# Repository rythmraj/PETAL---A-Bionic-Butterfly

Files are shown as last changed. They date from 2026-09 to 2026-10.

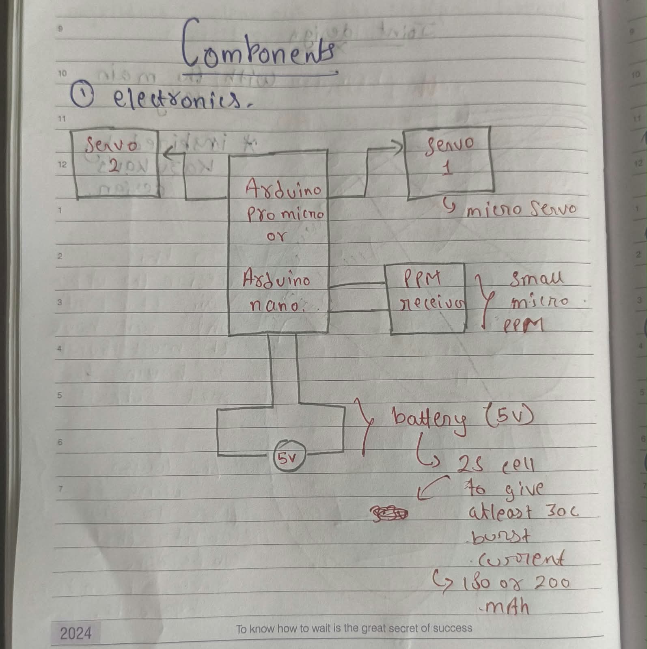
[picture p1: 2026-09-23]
Diary notes/WhatsApp Image 2026-09-23 at 20.36.07 (2).jpeg

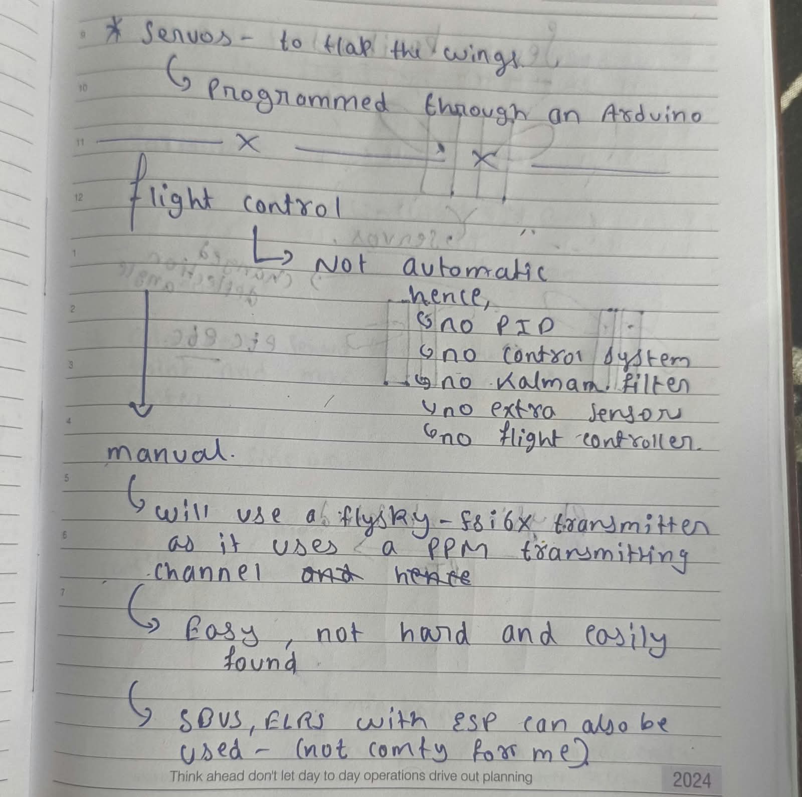
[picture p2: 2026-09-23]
Diary notes/WhatsApp Image 2026-09-23 at 20.32.57.jpeg

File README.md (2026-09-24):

Petal - A Bionic Butterfly

WhatsApp Image 2026-09-22 at 06 52 32 (1)

A small RC-controlled bionic butterfly built around an Arduino pro micro, two micro servos, and a FlySky receiver.

The project explores how a simple mechanical system can reproduce the flapping motion of a butterfly using coordinated servo movement. The firmware uses mathematical waveforms, including sine and triangular waves, to generate the wing motion.

The project is designed to be lightweight, reproducible, and easy to modify.

---

What Makes This Project Different?

Instead of simply reproducing an existing bionic butterfly build, this project focuses on understanding, modifying, and documenting the complete system, which provides guides for troubleshooting:

- Customised CAD design



- Personalised mechanical components
- Two-servo wing actuation

WhatsApp Image 2026-09-19 at 07 02 00 (2)

- Arduino pro micro or nano control
- FlySky RC control
- Sine-wave based wing motion
- Triangular-wave based wing motion
- Adjustable flapping parameters
- Documented electronics and wiring
- Reproducible build instructions
- Development and testing documentation

The project was developed iteratively, starting with individual servo tests and progressing toward the complete butterfly system.

---

Why I Made It

The idea for the Bionic Butterfly came to me after I saw some children in a park playing with butterflies and trying to catch them. It made me curious about whether I could recreate the movement of a butterfly using engineering rather than trying to replicate the entire animal. Later that same day, I came across mechanical design ideas and projects on GitHub, which inspired me to start designing my own version.
I wanted to understand how biological motion could be recreated using relatively simple electronics and mechanical components.
A butterfly is an interesting engineering problem because its wings require coordinated, repeated motion while remaining lightweight.
This project is also an experiment in learning engineering through building, documenting failures, and improving the design.

Inspiration:
Ken Jhonson's first butterfly design


Kazuhiko Kakuta - Butterfly and Ornitohopter designs.

Festo robotics company - Bionic blue butterfly


S-Diy and Ctorque tech youtube channel's modern design.

---
 How It Works

The butterfly uses two micro servos to drive the wings.
The Arduino Nano receives control input from a FlySky receiver and generates the corresponding servo positions.
The firmware can generate different motion profiles, like a sine wave,
a sinusoidal function is used to create smooth periodic wing movement.
servo_position = center + amplitude × sin(phase) (kinda like this, check the diary section for more info and also the firmware)
This produces relatively smooth acceleration and deceleration throughout the wing stroke.

---

Hardware

Component| Quantity

Arduino pro micro | 1

Micro servos (PTK 7465MG) | 2

FlySky receiver (FS - A8S) | 1

Flysky transmitter (flysky fsi6) | 1

2S battery (lipo, 180 or 220 or even 350 mAh, but should be lightweight, under 11-12g) (25c or 30c or higher) | 1

Butterfly mechanical structure| 1

See ""BOM.csv"" (BOM.csv) for the complete bill of materials, links, and total cost.

---

Electronics

The Arduino pro micro acts as the main controller.
The FlySky receiver provides the control input, while the two micro servos provide the mechanical actuation.
The complete wiring diagram is available here:
"Wiring Diagram" (Electronics/wiring_diagram.png)

For detailed wiring and connection information, see:
- ""Electronics/wiring_notes.md"" (Electronics/wiring_notes.md)

---

 CAD

The project contains the editable CAD source files, exported STEP files, and STL files required for fabrication.

CAD files

- "CAD/STL/" — printable STL files

---

Firmware

The firmware is written for the Arduino pro micro.

Main firmware:
The firmware controls the two servos and implements the wing-motion algorithms.

Current motion modes include:
- Sine wave
- Triangular wave (to be done)

The firmware is intentionally documented so that parameters such as amplitude, frequency, center position, and control response can be modified.

Development & Testing

The project was developed incrementally rather than assembling everything at once.

The development process included:

1. Testing individual servos 
2. Testing servo range and direction 
3. Testing Arduino control 
4. Testing receiver input ( to be done )
5. Developing the wing-motion algorithm 
6. Comparing motion profiles ( to be done )
7. Integrating the mechanical system ( to be done )
8. Testing the complete butterfly ( to be done )
9. Recording problems and modifications ( to be done )
10. Preparing the final reproducible design ( to be done )

Early experiments and test code are available in:

""Initial_Test/"" (Initial_Test/)

Development photographs and screenshots are available in:

""Images/"" (Images/)

---
 Development Diary (Highly recommend checking it to understand the workflow)

I maintained notes during the research and development process.
this is like a design history file, research to modification to questions, everything is there.
Scanned/photographed diary pages are available in:
"" Diary/ "" (Diary/)

The diary documents the development process, research, decisions, experiments, and iterations behind the project.

---

---

References & Credits

This project was developed while studying existing open-source bionic butterfly projects and related designs.
Existing work was used as reference and inspiration rather than being presented as original work.
Where an existing design was modified or incorporated, the original creator and source are credited in:
""Documentation/references.md"" (Documentation/references.md)
S-DiY Bionic Butterfly
The S-DiY bionic butterfly project was studied as a reference for the general mechanical/electronic concept.
Ctorque CAD Model
A CTorque model was used as a starting or perhaps as reference point for part of the CAD development. The modified or personalised version in this repository is identified in the CAD documentation.

All third-party work remains credited to its respective creators.

---

License

See ""LICENSE"" (LICENSE) for the licensing information applicable to the original work in this repository.

Third-party designs and references remain subject to their respective original licenses.

---

Project Status

Current status: Functional prototype / final design in development
The project has progressed from individual component testing to an integrated bionic butterfly system.
In the repository there are a few ( to be done ) marks present, as that is a future goal and will be completed as soon as possible to completely finish the build.

---

Author

Rythm Raj
Student / independent maker
This project was built as a personal engineering project to learn mechanical design, electronics, embedded programming, and iterative prototyping.

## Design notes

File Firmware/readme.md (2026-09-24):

# Firmware

## Hardware

- Arduino Pro Micro
- 2 micro servos
- FlySky receiver

## Motion Modes

The firmware currently supports:

1. Sine-wave wing motion
2. Triangular-wave wing motion (to be added)

## Uploading

1. Open `bionic_butterfly.ino` in Arduino IDE.
2. Select Arduino pro micro.
3. Select the appropriate processor/bootloader.
4. Select the correct COM/serial port.
5. Upload.

## Configuration

Motion parameters can be adjusted in the source code.

These include parameters such as:

- Servo center
- Servo amplitude
- Motion frequency
- Receiver input range
- Servo limits

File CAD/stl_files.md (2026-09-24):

my design changes:

instead of copying their design I went on to modify both of them according to my needs, 
for ctorque's design, I changes some dimensions and added "PETAL" engraving on the body of the desing;











Similarly with sdiy's design, i realised it could be a little pointy and sharp so i added my own iterations on it, used his dimension analysis only.
however, this design is not tested before, after testing if any changes required, i will post them here.



















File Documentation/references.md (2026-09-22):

References & Attribution

This project was developed through research into existing bionic butterfly projects, open-source CAD models, electronics implementations, and servo-control techniques.

I have intentionally documented external work used as references so that the original creators are not presented as part of my original work.

---

S-DiY Bionic Butterfly

The S-DiY bionic butterfly project was studied to understand the general concept of a two-servo bionic butterfly and its mechanical/electronic implementation.

The project influenced my understanding of the overall mechanism, but the firmware and implementation in this repository were developed separately.

Original project:

[(https://www.youtube.com/@SDiYchannel01)]

---

Ctorque CAD Model

A Ctorque CAD model was used as a starting/reference model for part of the mechanical design.
I modified the relevant model for my implementation and personalised the design by adding my own identifying/detail features.
Original model:

[https://www.youtube.com/@CTorque]

The repository does not claim the original base geometry as my original work.

---

Firmware References

The firmware was developed independently for this project. (Inspired by sdiy and kazukaku)
The implementation uses periodic mathematical functions, including sine-wave and triangular-wave motion, to control the servos.
Any external code, libraries, or algorithms used directly in the final implementation are listed below.



---

Other References / Research:

https://www.researchgate.net/figure/Butterfly-wing-structure-and-standard-of-length-measurement-A-Structures-and-names-of_fig1_355461952

https://dl.acm.org/doi/10.1145/3756423.3756506

https://dl.acm.org/doi/full/10.1145/3510459

---

Original Work in This Repository

The following parts represent my own project work:

- Project integration
- Mechanical modifications
- Personalised CAD features
- Electronics integration
- Wiring implementation
- Firmware implementation
- Servo-control logic
- Testing
- Iteration
- Build documentation
- Development diary
- Project photography and documentation

The repository distinguishes between referenced work and my modifications wherever applicable.

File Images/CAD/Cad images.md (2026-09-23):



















NOTE - DESIGNS ARE INSPIRED BY S-DIY AND CTORQUE CHANNEL, MAKE SURE TO CHECK THEM OUT FOR MORE PRECISE DIMENSIONS BASED DESIGNS.
(I cannot copy and paste their work here)







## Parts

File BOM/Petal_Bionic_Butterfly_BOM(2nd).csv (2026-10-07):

 | PETAL - A BIONIC BUTTERFLY (BOM)
 | DATE - 08-10-2026 |  | AUTHOR: RYTHM RAJ (@rythmmm on pixl)
S.NO. | Name | Quantity | buying link | price in INR | price in USD
1
2 | Arduino Pro Micro | 1 | https://www.amazon.in/gp/product/B0H9YZ9P35/ref=ewc_pr_img_1?smid=A31S66SMNGFXRB&psc=1 | 580 inr | 5.99 usd
3 | PTK 7465 MG-D 9g Servo | 2 | LOCAL SELLER (SCREENSHOTS ATTACHED) | 1500*2 = 3000 inr | 31.01 usd
4 | FlySky FS-i6 2.4GHz 6 Channel RC Transmitter | 1 | https://robu.in/product/flysky-fs-i6-2-4g-6ch-ppm-rc-transmitter-with-fs-ia6b-receiver/?gad_source=1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 | 5699 inr | 58.90 usd
5 | FlySky FS-A8S 2.4G 8CH Mini Receiver | 1 | https://www.amazon.in/gp/product/B0DP4WZFP2/ref=ox_sc_act_title_2?smid=AJ6SIZC8YQDZX&psc=1 | 1831 inr | 18.92 usd
6 | FABRIC(1) - Flowers Waterproof Floral Wrapping Paper | 1 | https://www.amazon.in/gp/product/B0DHSC99L6/ref=ewc_pr_img_1?smid=A11SOKBUQ5CS65&th=1 | 285 inr | 2.97 usd
7 | Carbon Fibre Rod (Solid) 1.5mm * 1000mm | 3 | https://robu.in/product/pultruded-carbon-fibre-rod-solid-1-5mm-1000mm-pack-of-4/ | 579*3 = 1737 inr | 17.95 usd
8 | Carbon Fibre Rod (Solid) 0.8mm * 1000mm | 2 | https://robu.in/product/pultruded-carbon-fibre-rod-solid-0-8mm-1000mm/ | 529*2 = 1058 inr | 10.93 usd
 | Battery Charger | 1 | https://www.amazon.in/gp/product/B0H41GF89X/ref=ewc_pr_img_1?smid=A3K0FQVTANK4PI&psc=1 | 299 inr | 3.09 usd
14 | Battery - 2s lipo, 180 or 220 mAh (2 batteries) | 2 | CANNOT FIND ONLINE, OFFLINE MARKET (RECEIPT WILL BE PRODUCED) [HARDWARE GRANT CAN COVER IT] |  | 10 usd
16 | 3d printing of parts (5 parts in total) | 5 | CANNOT FIND ONLINE, OFFLINE MARKET (RECEIPT WILL BE PRODUCED) [3D PRINTING GRANT CAN COVER IT] |  | 10 usd
17 | Wood laser cnc for one design | 1 | CANNOT FIND ONLINE, OFFLINE MARKET (RECEIPT WILL BE PRODUCED) [3D PRINTING GRANT CAN COVER IT] |  | 10 usd
 |  |  | Total = | 14,489 inr | 179.96 USD WITH GRANTS
 |  |  |  |  | 149.76 USD WITHOUT GRANTS

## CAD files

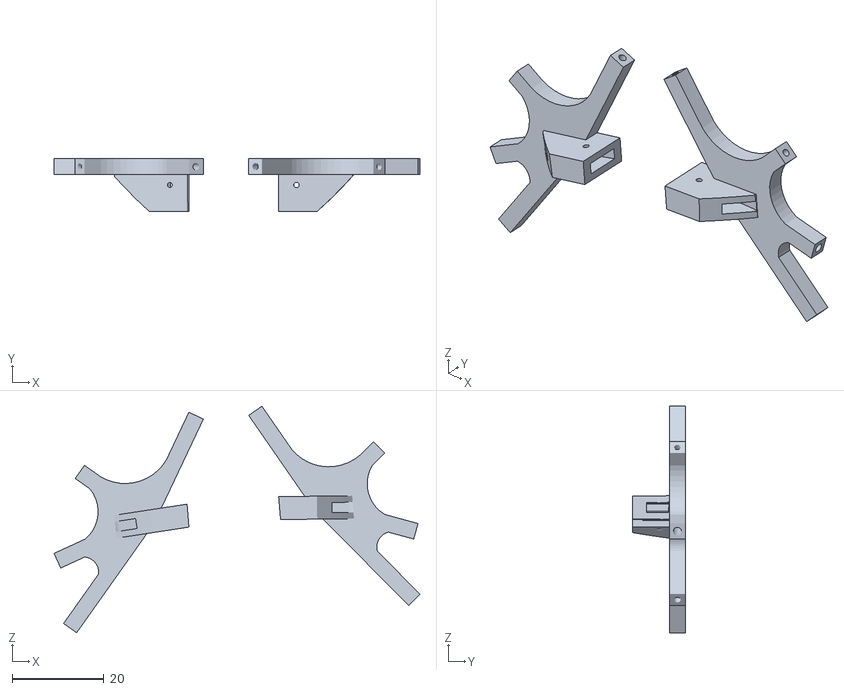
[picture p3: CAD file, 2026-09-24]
CAD/wing_mount.STL
79.7 x 11.5 x 49.3

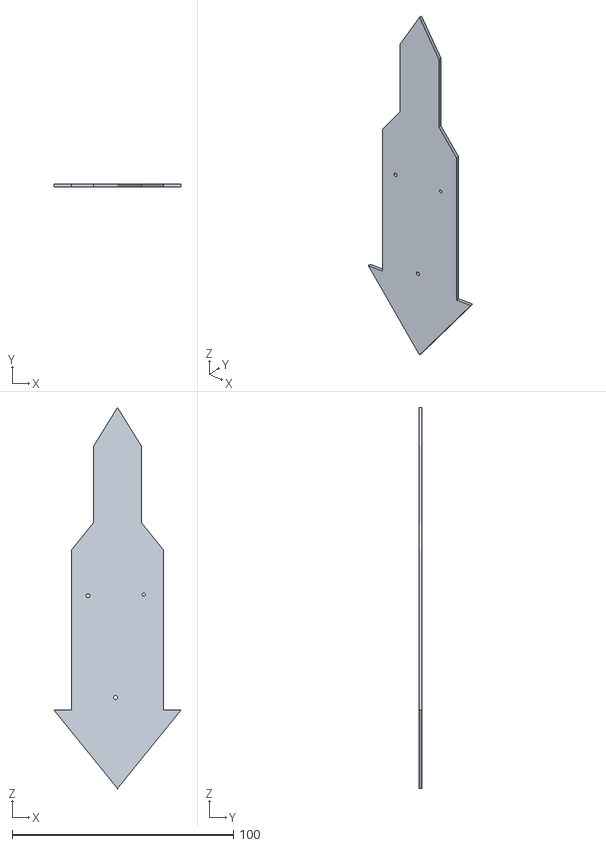
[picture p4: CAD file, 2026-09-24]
CAD/Pointy_design.stl
57.3 x 1.50 x 172.0

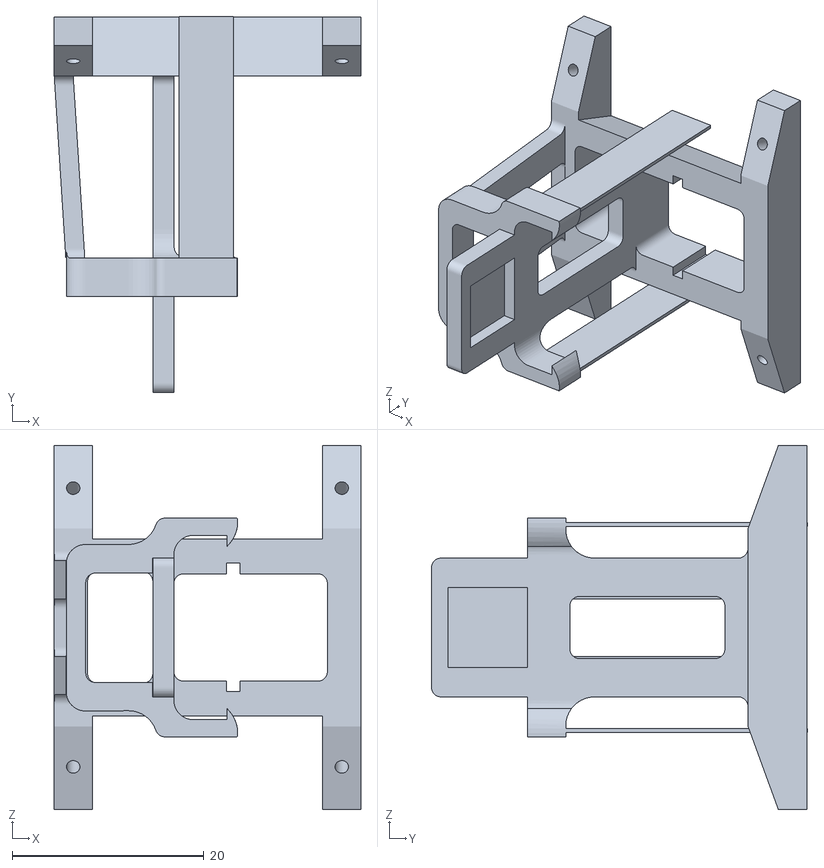
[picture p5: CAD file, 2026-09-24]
CAD/FC_Mount_V5_PETAL (1).stl
32.0 x 39.2 x 38.0

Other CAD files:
CAD/FC_Mount_V5_PETAL (1).f3d
CAD/Pointy_design.f3d

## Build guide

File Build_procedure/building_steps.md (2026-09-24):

IMPORTANT: THIS ENTIRE FILE IS IN "to be done" segment, as im still working to build the model, and when ill make it fly, 
i will update this as well with all the changes from
troubleshooting to change in wiring to everything.
I will also add images regarding the procedure in this file,

# Build Procedure

## 1. Print the parts

If you are going with the pointy design, print it, if you are going with fc design, print it as well.

## 2. Prepare the servos

mount the servos while matching the holes present on the body

## 3. Assemble the wing mechanism

use carbon fiber rods (1 to 0.5 mm as supports to assemble the wing) and then connect it to the connector

## 4. Install the Arduino

install the arduino board with the battery on to the body.

## 5. Install the receiver

install the receiver on the electronics as well (MKAE SURE TO REMOVE THE I-BUS OR S-BUS CHANNEL FROM THE RECEIVER, JUST REMOVE THE WIRE)

## 6. Wire the electronics

preferebly solder the wires to reduce weight of extras, connect it as shown on the diagram. 

## 7. Upload firmware

find the firmware on the firmware file in the repo.

## 8. Bind the transmitter

click on the binding button, and when the led on the receiver stops blinking and flashes a hard light, your transmitter is now binded with the receiver

## 9. Test the servos

the servos will move in opposite direction from each other and will change speed, pitch, frequency and angle as you change it on the respective channels on the transmitter.

## 10. Test the complete butterfly

(to be done)

## 11. Troubleshooting

Servo moving in wrong direction:
(to be done)

Servo jitter:
(to be done)

Wing hitting body:
(to be done)

Receiver not responding:
...

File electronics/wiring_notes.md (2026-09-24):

WhatsApp Image 2026-09-25 at 02 13 01

a 1S battery can also be used with a buck convertor (stepup)



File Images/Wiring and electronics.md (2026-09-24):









WIRING :



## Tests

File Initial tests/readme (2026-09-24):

# Initial Testing

IF YOU ARE USING THIS REPOSITORY TO BUILD YOUR OWN BIONIC BUTTERFLY, YOU DON'T NEED TO USE THIS FOLDER, ITS ONLY HERE TO DOCUMENT MY PROCESS.

This folder contains early experiments performed before the final firmware.

These tests were used to verify:

- Servo movement
- Servo direction
- Servo limits
- Arduino output
- Receiver input
- Initial wing-motion concepts

These files are development experiments and are not necessarily the final firmware.

The final implementation is located in `Firmware/`.

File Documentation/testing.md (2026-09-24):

This document is there to monitor the testing,
this will contain failures that (if) will happen during and after the building of petal
it will have the test name, expected result and the actual outcome
like:
test - left servo
expected - smooth movement
actual - (could be a positive result or a failure, both will be noted down)
its like journal with more technical terms and procedure,
if something failed, i will document the failure and  tell what i changed, this will even help other people who want to build their own bionic butterfly.

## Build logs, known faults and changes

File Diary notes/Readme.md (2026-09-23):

Development Diary

This folder contains photographs/scans of my physical development diary.

I used the diary to record research, ideas, calculations, design decisions, experiments, problems, and changes made during development.

The pages are kept in chronological order where possible.

The diary is included as development documentation rather than as a formal technical specification. The final technical information is maintained in the main project documentation.

Contents

- Research notes
- Initial ideas
- Mechanical design notes
- Servo experiments
- Firmware experiments
- Electronics notes
- Problems encountered
- Design changes
- Testing observations
- Future improvements

The photographs/scans are kept as close to the original notes as possible.

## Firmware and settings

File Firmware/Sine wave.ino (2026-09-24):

//This is the Sine wave version. The mechanism makes the servos move fast in the middle and slow down at the edges. 
// The advantage is a more lifelike flapping motion that saves energy, though the flapping speed and power are weaker than the Triangle wave version.
// Max Flap Angle	flapAmplitude	40 - 85	Sets the peak travel (degrees) from the 90° center point. Values above 80 may strain mechanical linkages.
// Pulse Width	attach(pin, 500, 2500)	500 - 2500 us	Extends physical servo travel. Verify that your servos support 2500us to avoid motor burnout.
// Flapping Speed	speedFactor	50 - 150	Mapped to the Throttle channel. Defines the phase increment per loop (Sine/Triangle wave frequency).
// i also added a lot of comments to actually explain the code to someone who has no idea about how it works.


/*
 PETAL - BIONIC BUTTERFLY
 
 
 
  RC Channels:
   CH1 -> steering
   CH2 -> elevator
   CH3 -> flapping speed
   CH5 -> steering trim
   CH6 -> pitch trim / perch control 
   CH7 -> perch switch (or any other emote maybe, perch is isnpired by s-diy)
 */

#include <Servo.h>
#include <PPMReader.h>


// pin config

const byte PPM_PIN = 3;

const byte LEFT_SERVO_PIN  = 9;
const byte RIGHT_SERVO_PIN = 10;


// ppm config

const byte CHANNEL_COUNT = 7;

PPMReader ppm(PPM_PIN, CHANNEL_COUNT);


// servo config

Servo servoLeft;
Servo servoRight;

const int CENTER_ANGLE = 90;


// flapping conif

// maxm movement away from center basically,
// 65 means -
// Left:  90 + 65 = 155 degrees
// Right: 90 - 65 = 25 degrees
// the servos move opposite each other,
// this produces the wing-flapping motion, duhhh(?) :>

const int FLAP_AMPLITUDE = 65;

// max pitch trim correction
const int MAX_PITCH_TRIM = 20;

// flight state

float phase = 0.0;
float perchPhase = 0.0;

float currentOffset = 0.0;

bool isPerching = false;
bool wasFailsafe = true;


// servo position tracking

int lastLeftPosition  = CENTER_ANGLE;
int lastRightPosition = CENTER_ANGLE;


// ppm filtering

// stored channel values are like;
// Index 0 = CH1
// Index 1 = CH2
// and so onto
// Index 6 = CH7

int lastChannelValues[CHANNEL_COUNT] = {
  1500,
  1500,
  1500,
  1500,
  1500,
  1500,
  1500
};


// lets ignore the small ppm fluctuations.
const int PPM_DEADBAND = 3;

// serial debugging

unsigned long lastLogTime = 0;

const unsigned long LOG_INTERVAL = 1000;


// SETUP (IMP)

void setup() {

  Serial.begin(115200);

  // attaching servos
  // 500–2500 gives the servo library a wide usable pulse range

  servoLeft.attach(LEFT_SERVO_PIN, 500, 2500);
  servoRight.attach(RIGHT_SERVO_PIN, 500, 2500);


  // start both servos at their neutral position

  servoLeft.write(CENTER_ANGLE);
  servoRight.write(CENTER_ANGLE);

  lastLeftPosition  = CENTER_ANGLE;
  lastRightPosition = CENTER_ANGLE;


  Serial.println();
  Serial.println(" PETAL IS READY TO TOUCH THE SKIES ");
  Serial.println(" 2 Servo Sine-Wave Mode");
  Serial.println("System is ready.");
}

// reading filtered ppm channels

int readPPMFiltered(byte channelIndex) {

  // ppmreader channels are numbered starting from 1
  int rawValue = ppm.latestValidChannelValue(
    channelIndex + 1,
    1500
  );


  // Ignoring tiny fluctuations again

  if (abs(rawValue - lastChannelValues[channelIndex]) > PPM_DEADBAND) {
    lastChannelValues[channelIndex] = rawValue;
  }


  return lastChannelValues[channelIndex];
}

// MAIN LOOP (imp)

void loop() {

  // checking receiver connections

  unsigned long ch3Raw = ppm.latestValidChannelValue(3, 0);

  bool receiverConnected = (ch3Raw != 0);


  // FAILSAFE

  if (!receiverConnected) {

    processFailsafe();

  }


  // normal flight

  else {

    // reading rc channels

    int steering = readPPMFiltered(0);
    int elevator = readPPMFiltered(1);
    int throttle = readPPMFiltered(2);

    int steeringTrim = readPPMFiltered(4);
    int pitchControl = readPPMFiltered(5);
    int perchSwitch  = readPPMFiltered(6);

    // steering

    int steerValue = 0;

    if (abs(steering - 1500) > 10) {

      steerValue = map(
        steering,
        900,
        2100,
        -15,
        15
      );
    }


    // CH5 adds additional steering trim

    int finalSteer =
      steerValue +
      map(
        steeringTrim,
        1000,
        2000,
        -15,
        15
      );


    // elevator

    int elevatorOffset = 0;

    if (abs(elevator - 1500) > 10) {

      elevatorOffset = map(
        elevator,
        900,
        2100,
        -15,
        15
      );
    }


    // pitch trim

    int pitchTrim = map(
      pitchControl,
      1000,
      2000,
      -MAX_PITCH_TRIM,
      MAX_PITCH_TRIM
    );


    // perch mode (can be changes in future to add a different emotes or mocing state or something petal can do)

    if (throttle > 1100) {

      // any throttle means normal flight

      isPerching = false;

    }

    else if (
      perchSwitch > 1600 &&
      throttle < 1100
    ) {

      isPerching = true;
    }


    // switch fully off meanss normal mode

    if (perchSwitch < 1400) {

      isPerching = false;
    }


    // determining flight mode

    if (isPerching) {

      updatePerchMode(pitchControl);

    }

    else if (throttle < 1050) {

      updateGlideMode();

    }

    else {

      updateSineFlapping(throttle);
    }


    // calculating servo position

    int leftOutput =
      CENTER_ANGLE +
      (int)currentOffset +
      finalSteer +
      elevatorOffset +
      pitchTrim;


    int rightOutput =
      CENTER_ANGLE -
      (int)currentOffset +
      finalSteer -
      elevatorOffset -
      pitchTrim;


    // update servos

    updateServos(
      leftOutput,
      rightOutput
    );
  }

  // serial debug output


  if (millis() - lastLogTime > LOG_INTERVAL) {

    lastLogTime = millis();

    if (receiverConnected) {

      Serial.print("[CONNECTED] ");
      Serial.print("CH3: ");
      Serial.println(lastChannelValues[2]);

    }

    else {

      Serial.println("[!] NO SIGNAL - FAILSAFE");
    }
  }


  // mall delay to keep the control loop stable, pr else the flapping will be uncontrolled

  delay(4);
}

// SINE WAVE FLAPPING

void updateSineFlapping(int throttle) {

  // when recovering from failsafe/glide/perch,
  // restart the sine wave from the opposite side.

  if (wasFailsafe) {

    phase = PI;
    wasFailsafe = false;
  }


  // converting throttle into flapping speed.

  float speedFactor =
    map(
      throttle,
      1050,
      2000,
      60,
      100
    ) / 1000.0;


  // advance sine-wave phase.

  phase += speedFactor;


  // keeping phase between 0 and 2PI, (Yes its the 3.14150... PI)

  if (phase >= 2 * PI) {

    phase -= 2 * PI;
  }


  // calculate wing movement.

  currentOffset =
    sin(phase) * FLAP_AMPLITUDE;
}

// PERCH MODE

void updatePerchMode(int rawPitchControl) {

  wasFailsafe = true;


  // CH6 controls maximum upward angle

  float maxUpAngle =
    map(
      rawPitchControl,
      1000,
      2000,
      30,
      60
    );


  // slowly oscillating the wings

  perchPhase += 0.01;


  float goalAngle =
    maxUpAngle +
    (sin(perchPhase) * 20.0) -
    20.0;


  // smoothly moving

  if (abs(currentOffset - goalAngle) > 0.5) {

    if (currentOffset < goalAngle) {

      currentOffset += 1.5;

    }

    else {

      currentOffset -= 1.5;
    }
  }
}

// glide mode

void updateGlideMode() {

  wasFailsafe = true;


  // gradually returning the wings to the center

  if (currentOffset < 0) {

    currentOffset += 2.0;
  }

  else if (currentOffset > 0) {

    currentOffset -= 2.0;
  }


  // stop tiny movements

  if (abs(currentOffset) < 2.5) {

    currentOffset = 0;
  }
}

// FAILSAFE

void processFailsafe() {

  // slowly bringing wings back toward neutral

  if (currentOffset < 0) {

    currentOffset += 1.5;
  }

  else if (currentOffset > 0) {

    currentOffset -= 1.5;
  }


  if (abs(currentOffset) < 1.5) {

    currentOffset = 0;
  }


  // neutral servo positions

  updateServos(
    CENTER_ANGLE + (int)currentOffset,
    CENTER_ANGLE - (int)currentOffset
  );


  wasFailsafe = true;
}

// updating the servos

void updateServos(
  int targetLeft,
  int targetRight
) {

  // preventing mechanical over travel

  targetLeft =
    constrain(
      targetLeft,
      5,
      175
    );


  targetRight =
    constrain(
      targetRight,
      5,
      175
    );


  // only sending a new position when movement is required

  if (
    abs(targetLeft - lastLeftPosition) >= 1
  ) {

    servoLeft.write(targetLeft);

    lastLeftPosition = targetLeft;
  }


  if (
    abs(targetRight - lastRightPosition) >= 1
  ) {

    servoRight.write(targetRight);

    lastRightPosition = targetRight;
  }
}

/*
FlySky Receiver          Arduino Nano
--------------------------------------
PPM    ------->  D3
GND            ------->  GND

Left Servo signal ------> D9
Right Servo signal -----> D10

Servo GND --------------> GND
Servo V+ ---------------> External 5-6V supply (if not then use the arduin's channel only)

check whether your particular FlySky receiver outputs PPM, 
the code above is specifically for PPM for instance i-BUS is a different protocol and 
would require different code/wiring.

For your first bench test, keep 'FLAP_AMPLITUDE = 65' in the code 
but don't immediately run it at full throttle with the wings attached. 
first verify that both servos move symmetrically from roughly from 25 degrees to 155 degrees, 
that the transmitter controls behave correctly, 
and that the two servo directions match your physical mechanism.
*/

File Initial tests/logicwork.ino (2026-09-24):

/*
so basically thats a servo for the left part or the left servo

#pin numbers:
const int LEFT_SERVO_PIN = 9;
const int RIGHT_SERVO_PIN = 10;

basically defining the pin number of each of the created objects

int - integer
so, 
int LEFT_SERVO_PIN = 9;
but what is a const

const is basically defining the object as a constant
so, if
const int LEFT_SERVO_PIN = 9;
than it means - do not change it later.
basically we are telling the arduino that this will not change later.

center position :

const int LEFT_CENTER = 90;
const int LEFT_CENTER = 90;

we are telling the arduino that when the servo is at 90 degrees, consider that the center.

typically, 0d-left - 90d-center - 180d-right

we can go with something like this as well - 55 - 90 - 125

#flapping angle

honestly, the most important variable for our experiment.

cost int FLAP_ANGLE = 35;

basically, move the servo upto 35 degrees away from its center position
hence it goes from 90 to left 55 to back to 90 to 125 to right.


#flap period

const int FLAP_PERIOD = 800;

not actually doing anything. it was intended to represent the time associated with one complete flap cycle.
but not for the test subject.

#update delay

after giving the servo a new position, wait 10millisec before giving it the next position

#setup()

void setup()
{

arduino runs this once when it starts

bascially - 

arduino turns on - setup() - initialization - loop() - loop() - loop().....

basically, before you start doing the actuall job, get everything ready.

# connecting the servo to the pin, using attach command

inside setup :
leftwing.attach(left_servo_pin);

so it means;

leftwing.attach(9)

it is - the left servos control signal is connected to arduino pin 9

attaching the left_servo_wing variable to the other object that is leftwing

#put both wings at center, using write command

leftwing.write(LEFT_CENTER)
which basically is leftwing.write(90)

also delay is the same,

delay(1000);
where it is in miliseconds

LOOPs

void loop()

basic - everything inside it repeats forever.

for (int angle =0; angle= flap agnle; angle++ )

basically, 
for loop is - repeat something while counting

for(start;condition;change)

for(
    int angle = 0;
    angle <= FLAP_ANGLE;
    anglee++ 

)


angle++ is as same as angle=angle+1
basically add 1
it maks the servo gradually moves from 90 to 125

we used for the right servo - rightwing.write(right_center - angle)

so,
angle = 0 
90-0 = 90
angle = 1
90-1=89
and so on....

we want the servos to move in opposite directions, thats why one is decreasing and the other is increasing



the final for loop;
for (int angle = -FLAP_ANGLE; angle ,<= 0; angle++)

this basically is the movement of the wing back to its initial setup

and then the loop starts again.

lets understand the program in human language:

- arduino, please learn how to control servos
- i have two servos, call one leftwing and the other one rightwing.
- the left servo is connected to pin 9
- the right servo is connected to pin 10
- their center position in 90
- i want them to move 35 degress away from the center
- when you start, put both servo at 90 degrees and wait one sec
- then repeatedly;
- move the left servo gradually from 90 towards 125
- at the same time, move the right servo from 90 to towards 55
- then move both servos through the center toward the opposite extreme
- then bring them back toawrd the center.
- and then repeat forever



important part -
#include - bring in a library
servo.h -  a library
servo - servo control object/type
int -  integer
const - constant, value shouldn't change
"=" - assign a value
void setup() - runs once
void loop() - runs forever
.attach() - connect servo to the pin
.writer() -  command servo position
delay() -  wait
for - repeat something while counting
++ - add 1
-- - subtract 1
+ - addition
- - substraction
{} - defines a block of code
// -  comment

*/

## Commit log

2026-09-18 Update README with project details and status
    Added detailed project overview, inspiration, planned hardware, and current status for the Bionic Butterfly project.
2026-09-19 Add readme for servo test code
    Added a readme file detailing test code for Arduino Uno and SG90 servos, including purpose and reference to main code.
2026-09-23 Create CAD
2026-09-23 Create Cad images
2026-09-23 Rename Cad images to Cad images.md
2026-09-23 Update Cad images.md
2026-09-23 Create Wiring and electronics
2026-09-24 Update Wiring and electronics
2026-09-24 Add wiring image to Wiring and electronics document
2026-09-24 Update wiring notes with battery information
    Added note about using a 1C battery with a buck converter.
